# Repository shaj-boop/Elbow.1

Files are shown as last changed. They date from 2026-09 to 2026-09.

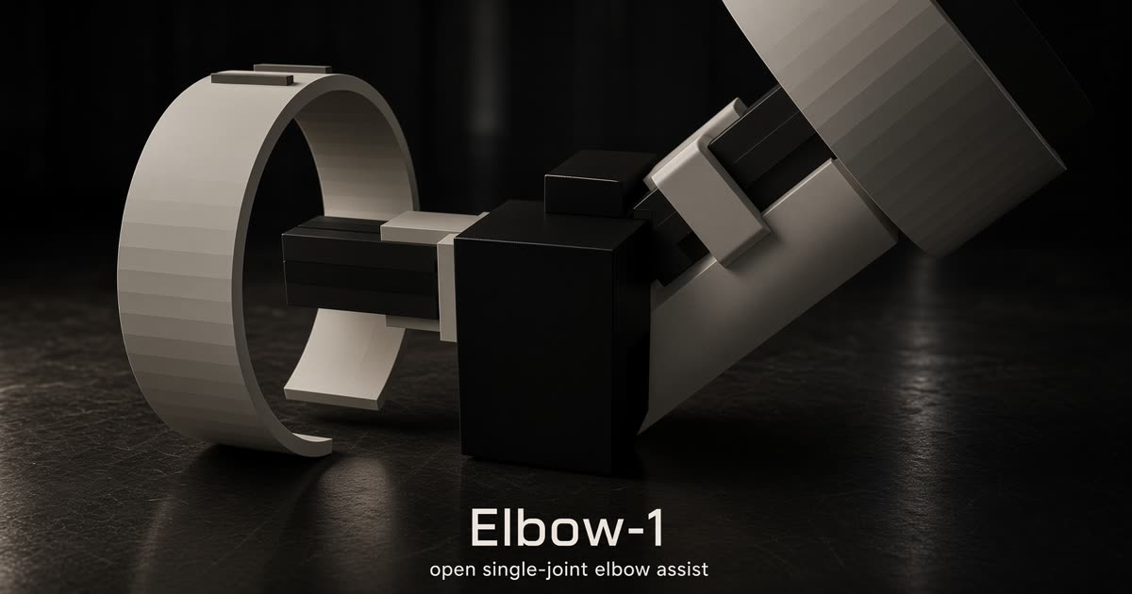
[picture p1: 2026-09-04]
og.jpg

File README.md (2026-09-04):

# Elbow-1

An open single-joint elbow assist. One degree of freedom. One working elbow.

CAD freeze **v0** for a Solo Grant application (ask: **$1,000**). The grant buys two ROBOTIS Dynamixel MX-28AT actuators and the cuff, sensors, and e-stop around them.

Builder: **Dmitrii Naumov**, solo.

**Not a medical device.** Not a clinic product. Not a full-body suit.

| | |
|---|---|
| Stage | CAD + firmware skeleton. Actuators not purchased. |
| Ask | $1,000 |
| DoF | 1 (elbow) |
| Actuators | MX-28AT ×2 (agonist / antagonist) |
| License | CERN-OHL-S v2 (hardware) / MIT (firmware) |

## What v1 is

- One elbow, not a suit
- Two MX-28AT actuators (position + PID in the box, 2.5 N·m stall at 12 V)
- 3D-printed PETG cuffs on a short 2020 aluminum frame
- Load cell in the load path
- Arduino firmware that will not move unless the e-stop is armed
- Bench test: hold 2 kg through 90°, log angle and load to CSV
- Then the same test on an arm

## Repo layout

```
cad/elbow1.scad          OpenSCAD source (parametric)
cad/stl/                 Printable parts
firmware/Elbow1.ino      Arduino + Dynamixel Shield
firmware/config.h        Pins, IDs, torque cap
BOM.md                   Priced parts, Sep 2026
BUILD.md                 Four-week plan after parts land
SAFETY.md                E-stop, torque cap, no medical claims
CONSTRAINTS.md           What v1 will not grow into
GRANT.md                 Written application
FORM_ANSWERS.md          Airtable paste sheet
LICENSE                  CERN-OHL-S / MIT
```

## Print recipe

PETG · 0.2 mm layer · 5 perimeters · 40% gyroid.

| Part | File |
|---|---|
| Upper-arm cuff (ID 96 mm) | `cad/stl/cuff_upper.stl` |
| Forearm cuff (ID 80 mm) | `cad/stl/cuff_forearm.stl` |
| Horn adapter ×2 | `cad/stl/horn_adapter.stl` |
| Load-cell bracket | `cad/stl/loadcell_bracket.stl` |
| Extrusion clip ×2 | `cad/stl/extrusion_clip.stl` |

Open `cad/elbow1.scad` in [OpenSCAD](https://openscad.org). `part = "assembly";` shows the hinge.

## Firmware

Arduino Uno + Dynamixel Shield. Serial 115200.

```
ARM / DISARM / MOVE <deg> / CYCLE / LOG ON
```

Torque stays off until the latching e-stop is armed. See `SAFETY.md`.

## After the money lands

See `BUILD.md`. Order both MX-28ATs on day 0. Week 2 is the 2 kg / 90° bench. Week 4 is publish — or an honest miss.

## Working stage

- [x] Constraint list (one joint, no suit)
- [x] BOM priced with live sources, Sep 2026
- [x] Safety rules
- [x] OpenSCAD assembly + printable STLs
- [x] Arduino firmware skeleton (will not move unarmed)
- [x] Bench protocol: 2 kg through 90°, three cycles, CSV
- [ ] MX-28AT ×2 purchased — this is the wall
- [ ] Week 1: one motor, e-stop in the enable line
- [ ] Week 2: 2 kg / 90° logged on the bench
- [ ] Week 3: PETG cuffs on a padded dummy, then an arm
- [ ] Week 4: publish video + CSV, or an honest miss

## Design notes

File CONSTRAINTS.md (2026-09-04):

# Constraints — what v1 is not

- Not a suit. One elbow.
- Not two arms. Not a shoulder. Not a hand.
- Not Dynamixel-X series, not Maxon, not a custom cycloidal. MX-28AT ×2 is the joint.
- Not CNC aluminum cuffs in v1. PETG + webbing. If PETG cracks, that is data.
- Not ROS as a requirement. Arduino + a serial log on the Mac mini is enough.
- Not a paper. A video, a CSV of angle/load, and the CAD.

If a sentence starts with "later we could add hips," it does not belong in this grant.

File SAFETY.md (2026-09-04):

# Safety — Elbow-1

v1 is a bench joint that may later go on one adult arm. It is not a medical device.

## Hard rules

1. **E-stop is armed or the motors do not enable.** Latching mushroom, wired so a software crash still kills drive.
2. **Torque cap in firmware** below stall. MX-28AT stall is 2.5 N·m at 12 V. v1 command limit is well under that.
3. **No backdrive fight.** If the load cell sees an unexpected spike, disable.
4. **Bench first.** 2 kg through 90° in a fixture, logged, before any worn test.
5. **Worn test is optional and slow.** Padded cuffs, second person present, e-stop in the free hand.
6. **No medical claims.** No rehab protocol. No patient. No "for disability" marketing in v1.

## What this is not

A full-body exo. A factory cobot. A product. A way around a clinic.

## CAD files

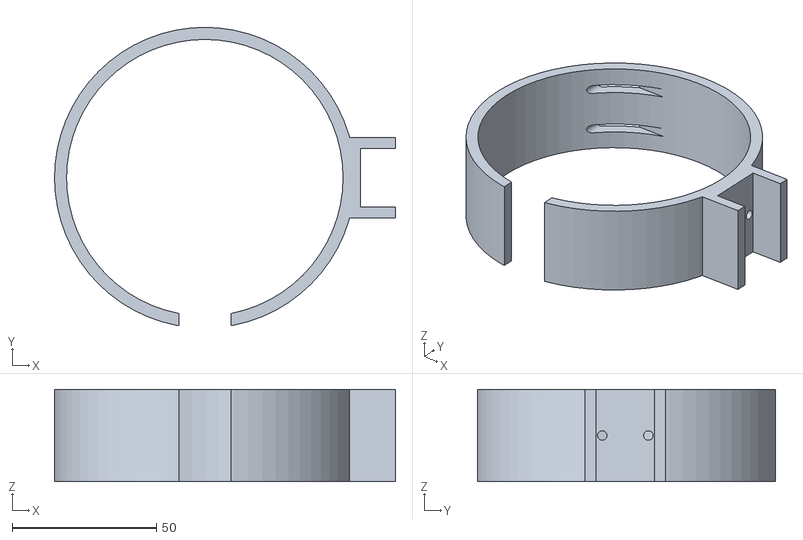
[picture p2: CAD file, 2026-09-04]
cuff_upper.stl
118.4 x 103.6 x 32.0

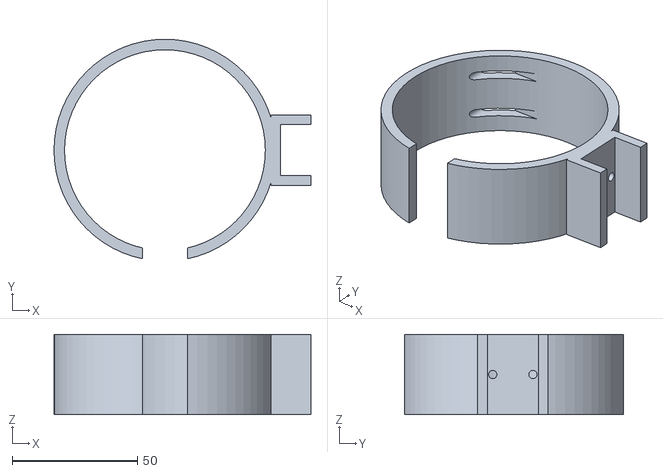
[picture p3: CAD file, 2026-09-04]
cuff_forearm.stl
102.4 x 87.5 x 32.0

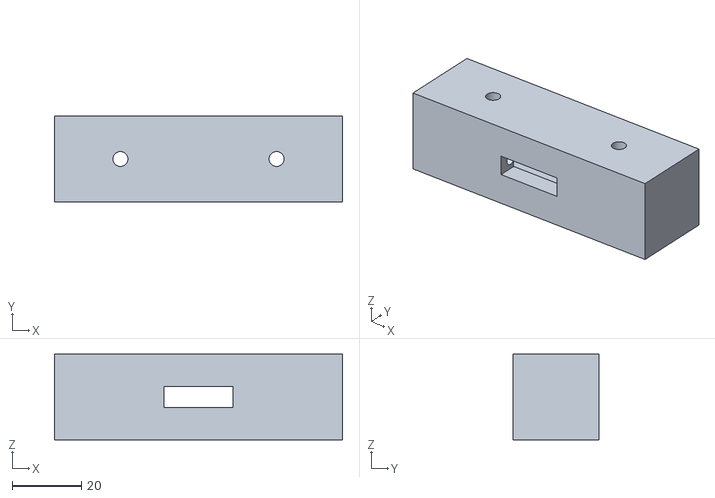
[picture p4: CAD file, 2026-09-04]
loadcell_bracket.stl
83.0 x 24.7 x 24.7

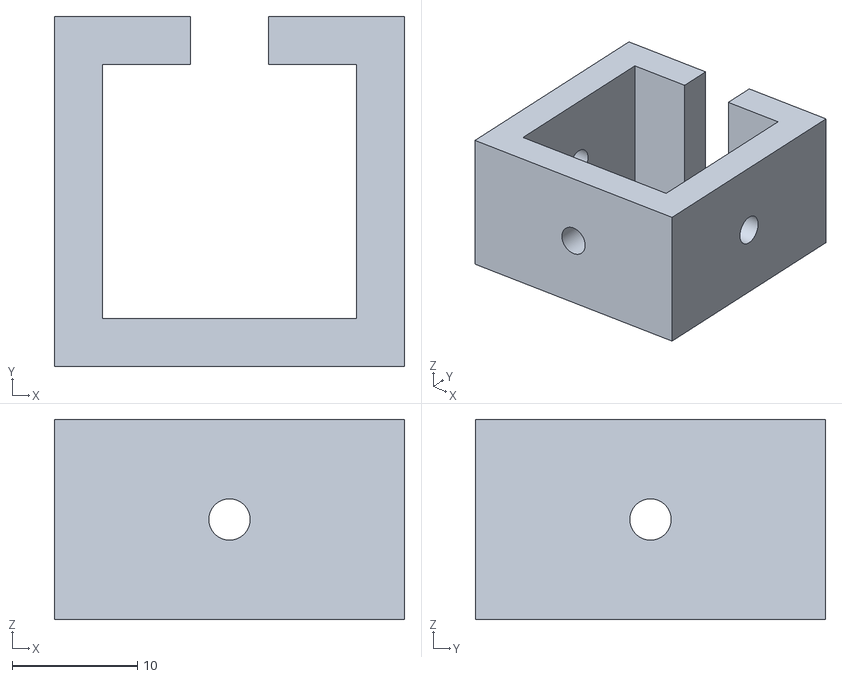
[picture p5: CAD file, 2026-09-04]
extrusion_clip.stl
28.0 x 28.0 x 16.0

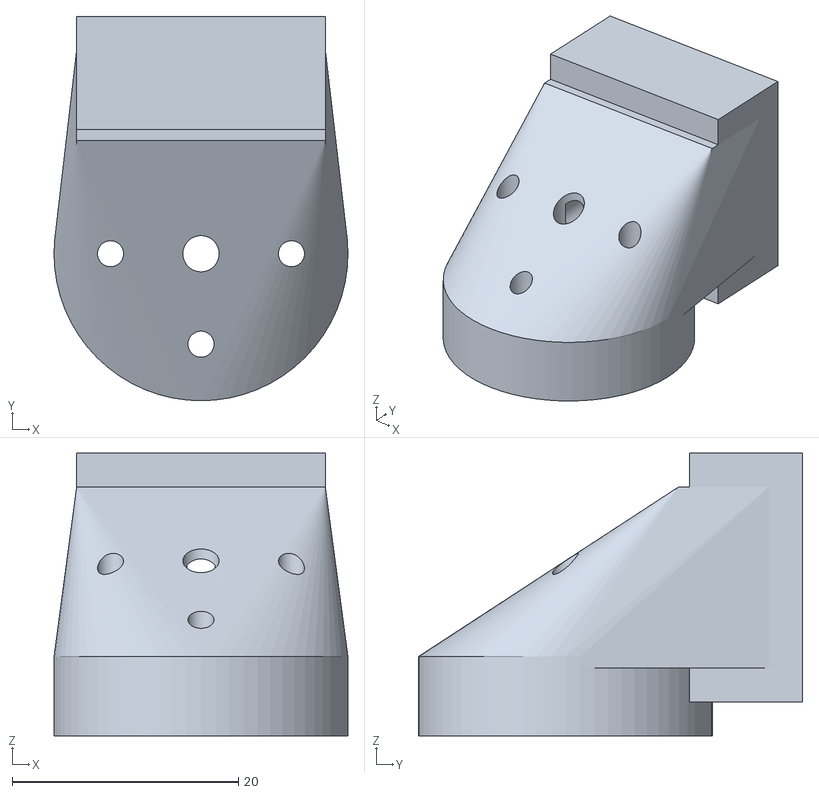
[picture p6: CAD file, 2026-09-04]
horn_adapter.stl
26.0 x 34.0 x 25.0

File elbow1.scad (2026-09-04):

// Elbow-1 — open single-joint elbow assist
// Print PETG, 0.2 mm, 5 perimeters, 40% gyroid.
// MX-28AT body: 35.6 x 50.6 x 35.5 mm (ROBOTIS).
// Units: millimetres. Origin: assembly midline.

$fn = 64;

part = "assembly"; // cuff_upper | cuff_forearm | horn_adapter | loadcell_bracket | extrusion_clip | dummy_mx28 | assembly

// --- MX-28AT ---
mx_w = 35.6;
mx_h = 50.6;
mx_d = 35.5;
horn_r_holes = 8.0;     // M2 holes on MX horn
horn_od = 22.0;
horn_screw = 3.2;

// --- 2020 ---
ext = 20;
ext_slot = 6.2;

// --- load cell 20 kg aluminium bar (typical) ---
lc_l = 75;
lc_w = 12.7;
lc_h = 12.7;
lc_hole = 4.3;
lc_hole_inset = 15;

// --- cuffs (adult) ---
upper_id = 96;
fore_id  = 80;
cuff_t   = 4.2;
cuff_w   = 32;
web_w    = 25;
web_t    = 3.2;

module mx28_dummy() {
    color("#2a2a2a")
        cube([mx_w, mx_d, mx_h], center=true);
    color("#c9a227")
        translate([0, mx_d/2 + 1.2, mx_h*0.18])
            rotate([90,0,0])
                cylinder(h=2.4, d=horn_od, center=true);
}

module horn_adapter() {
    // Sits on MX horn, presents a 2020-facing plate with 4x M3.
    difference() {
        union() {
            cylinder(h=6, d=horn_od + 4);
            translate([0,0,6])
                hull() {
                    cylinder(h=1, d=horn_od + 4);
                    translate([0, 14, 8])
                        cube([22, 8, 16], center=true);
                }
            translate([0, 16, 14])
                cube([22, 10, 22], center=true);
        }
        // horn screw
        translate([0,0,-1]) cylinder(h=20, d=horn_screw);
        // 4x M2 on horn
        for (a = [0:90:270])
            rotate([0,0,a])
                translate([horn_r_holes, 0, -1])
                    cylinder(h=20, d=2.3);
        // 2020 pocket
        translate([0, 22, 14])
            cube([ext + 0.4, 12, ext + 0.4], center=true);
        // M3 through 2020
        translate([0, 16, 14])
            rotate([90,0,0])
                cylinder(h=30, d=3.3, center=true);
        // M3 nut trap
        translate([0, 12, 14])
            rotate([90,0,0])
                cylinder(h=3.2, d=6.2, center=true, $fn=6);
    }
}

module cuff(inner) {
    outer = inner + 2*cuff_t;
    split = 18;
    difference() {
        union() {
            cylinder(h=cuff_w, d=outer);
            // 2020 boss
            translate([outer/2 + 6, 0, cuff_w/2])
                cube([16, 28, cuff_w], center=true);
        }
        translate([0,0,-1]) cylinder(h=cuff_w+2, d=inner);
        // split for flex / webbing close
        translate([0, -outer/2, cuff_w/2])
            cube([split, outer, cuff_w+2], center=true);
        // webbing slots
        for (z = [8, cuff_w-8]) {
            translate([-inner/4, inner/2 - 2, z])
                rotate([90,0,0])
                    hull() {
                        translate([-web_w/2 + 1.5, 0, 0]) cylinder(h=20, d=web_t);
                        translate([ web_w/2 - 1.5, 0, 0]) cylinder(h=20, d=web_t);
                    }
        }
        // M3 pair into 2020 boss
        translate([outer/2 + 6, 8, cuff_w/2])
            rotate([0,90,0]) cylinder(h=24, d=3.3, center=true);
        translate([outer/2 + 6,-8, cuff_w/2])
            rotate([0,90,0]) cylinder(h=24, d=3.3, center=true);
        // 2020 pocket in boss
        translate([outer/2 + 12, 0, cuff_w/2])
            cube([ext+0.3, ext+0.3, cuff_w+2], center=true);
    }
}

module cuff_upper()    { cuff(upper_id); }
module cuff_forearm()  { cuff(fore_id); }

module loadcell_bracket() {
    wall = 4;
    difference() {
        translate([0,0,0])
            cube([lc_l + 8, lc_w + 12, lc_h + wall + 8], center=true);
        // pocket
        translate([0,0, wall/2])
            cube([lc_l + 0.4, lc_w + 0.4, lc_h + 0.4], center=true);
        // through for wiring
        cube([20, lc_w + 14, 6], center=true);
        // M4 holes matching bar
        for (x = [-lc_l/2 + lc_hole_inset, lc_l/2 - lc_hole_inset])
            translate([x, 0, 0])
                cylinder(h=40, d=lc_hole, center=true);
        // M3 to 2020 on the back
        for (y = [-8, 8])
            translate([0, y, 0])
                rotate([0,90,0])
                    cylinder(h=40, d=3.3, center=true);
    }
}

module extrusion_clip() {
    difference() {
        cube([28, 28, 16], center=true);
        cube([ext+0.35, ext+0.35, 18], center=true);
        rotate([90,0,0]) cylinder(h=40, d=3.3, center=true);
        rotate([0,90,0]) cylinder(h=40, d=3.3, center=true);
        // slot mouths
        translate([0, ext/2 + 4, 0]) cube([ext_slot, 10, 18], center=true);
    }
}

module assembly() {
    // two MX-28 as agonist / antagonist about the elbow axis
    translate([0,  28, 0]) rotate([0,90,0]) mx28_dummy();
    translate([0, -28, 0]) rotate([0,90,180]) mx28_dummy();
    color("#d8d2c4") {
        translate([-70, 0, 42]) rotate([90,0,90]) cuff_upper();
        translate([ 78, 0, 36]) rotate([90,0,90]) cuff_forearm();
        translate([0, 28, mx_h/2 + 8]) horn_adapter();
        translate([0,-28, mx_h/2 + 8]) rotate([0,0,180]) horn_adapter();
        translate([0, 0, -36]) loadcell_bracket();
        translate([-40, 0, 10]) extrusion_clip();
        translate([ 40, 0, 10]) extrusion_clip();
    }
    // 2020 spars (visual)
    color("#8a8a8a") {
        translate([-48, 0, 10]) cube([80, 20, 20], center=true);
        translate([ 52, 0, 10]) cube([70, 20, 20], center=true);
    }
}

if (part == "cuff_upper")       cuff_upper();
else if (part == "cuff_forearm") cuff_forearm();
else if (part == "horn_adapter") horn_adapter();
else if (part == "loadcell_bracket") loadcell_bracket();
else if (part == "extrusion_clip") extrusion_clip();
else if (part == "dummy_mx28")   mx28_dummy();
else                            assembly();

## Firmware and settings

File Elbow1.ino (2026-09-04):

// Elbow-1 firmware v0.1 — Arduino Uno + Dynamixel Shield
// Will not enable torque unless the e-stop is armed.
//
// Serial 115200. Commands:
//   ARM          — torque on if e-stop is high
//   DISARM       — torque off
//   MOVE <deg>   — 0..90, both actuators, torque-capped
//   CYCLE        — three 0→90→0 sweeps (Week 2 protocol)
//   LOG ON|OFF   — CSV: t_ms,angle_deg,load_n,flex,ext,estop
//
// If it fails, the failure is in the log too.

#include <Dynamixel2Arduino.h>
#include "HX711.h"
#include "config.h"

Dynamixel2Arduino dxl(DXL_SERIAL, DXL_DIR_PIN);
HX711 scale;

bool armed = false;
bool logging = false;
uint32_t t0 = 0;
float goalDeg = 0;

uint16_t degToTick(float deg) {
  if (deg < 0) deg = 0;
  if (deg > 90) deg = 90;
  return (uint16_t)(POS_ZERO + deg * (TICKS_PER_REV / 360.0f));
}

bool estopArmed() {
  return digitalRead(ESTOP_PIN) == HIGH;
}

void torqueOff() {
  dxl.torqueOff(ID_FLEX);
  dxl.torqueOff(ID_EXT);
  armed = false;
  digitalWrite(LED_ARMED, LOW);
}

bool torqueOn() {
  if (!estopArmed()) {
    torqueOff();
    Serial.println(F("# ESTOP open — not arming"));
    return false;
  }
  dxl.writeControlTableItem(TORQUE_LIMIT, ID_FLEX, TORQUE_LIMIT);
  dxl.writeControlTableItem(TORQUE_LIMIT, ID_EXT,  TORQUE_LIMIT);
  dxl.torqueOn(ID_FLEX);
  dxl.torqueOn(ID_EXT);
  armed = true;
  digitalWrite(LED_ARMED, HIGH);
  Serial.println(F("# armed"));
  return true;
}

void goDeg(float deg) {
  if (!armed) return;
  goalDeg = deg;
  uint16_t t = degToTick(deg);
  dxl.setGoalPosition(ID_FLEX, t);
  dxl.setGoalPosition(ID_EXT,  TICKS_PER_REV - t); // antagonist
}

float readLoadN() {
  if (!scale.is_ready()) return 0;
  return scale.get_units(1) * 9.80665f / 1000.0f; // gram-ish cal → N
}

void setup() {
  pinMode(ESTOP_PIN, INPUT_PULLUP);
  pinMode(LED_ARMED, OUTPUT);
  digitalWrite(LED_ARMED, LOW);

  Serial.begin(115200);
  dxl.begin(DXL_BAUD);
  dxl.setPortProtocolVersion(DXL_PROTOCOL);

  scale.begin(HX711_DOUT, HX711_SCK);
  scale.set_scale(1.0f / SCALE_N_PER_COUNT);
  scale.tare();

  torqueOff();
  Serial.println(F("# Elbow-1 v0.1  e-stop must be armed"));
  Serial.println(F("t_ms,angle_deg,load_n,flex,ext,estop"));
  t0 = millis();
}

void loop() {
  if (!estopArmed() && armed) {
    torqueOff();
    Serial.println(F("# ESTOP — torque off"));
  }

  float load = readLoadN();
  if (armed && fabs(load) > SPIKE_N) {
    torqueOff();
    Serial.print(F("# spike N="));
    Serial.println(load);
  }

  if (logging && (millis() % LOG_MS) < 2) {
    Serial.print(millis() - t0); Serial.print(',');
    Serial.print(goalDeg); Serial.print(',');
    Serial.print(load, 3); Serial.print(',');
    Serial.print(dxl.getPresentPosition(ID_FLEX)); Serial.print(',');
    Serial.print(dxl.getPresentPosition(ID_EXT)); Serial.print(',');
    Serial.println(estopArmed() ? 1 : 0);
  }

  if (Serial.available()) handleLine();
}

void handleLine() {
  String line = Serial.readStringUntil('\n');
  line.trim();
  if (line.equalsIgnoreCase("ARM")) { torqueOn(); return; }
  if (line.equalsIgnoreCase("DISARM")) { torqueOff(); return; }
  if (line.startsWith("MOVE")) {
    goDeg(line.substring(4).toFloat());
    return;
  }
  if (line.equalsIgnoreCase("CYCLE")) {
    if (!torqueOn()) return;
    logging = true;
    for (uint8_t c = 0; c < 3; c++) {
      goDeg(90); delay(2500);
      goDeg(0);  delay(2500);
    }
    torqueOff();
    Serial.println(F("# cycle done"));
    return;
  }
  if (line.equalsIgnoreCase("LOG ON"))  { logging = true;  t0 = millis(); }
  if (line.equalsIgnoreCase("LOG OFF")) { logging = false; }
}

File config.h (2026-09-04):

#pragma once
// Elbow-1 — pin map and hard limits.
// MX-28AT stall is 2.5 N·m at 12 V. Command cap sits well under that.

#include <stdint.h>

static const uint8_t ID_FLEX = 1;
static const uint8_t ID_EXT  = 2;

// Dynamixel Shield on Uno: UART via the onboard buffer.
#define DXL_SERIAL   Serial
#define DXL_DIR_PIN  2
static const float DXL_PROTOCOL = 1.0f;
static const uint32_t DXL_BAUD  = 1000000;

// MX-28: 12-bit, 4096 ticks / rev.
static const uint16_t TICKS_PER_REV = 4096;
static const uint16_t POS_ZERO      = 2048;          // 0°
static const uint16_t POS_FLEX90    = 2048 + 1024;   // 90°

// Torque cap: 1.2 N·m ≈ 48% of stall. Register units 0–1023.
static const uint16_t TORQUE_LIMIT = 490;

// Latching mushroom. Hardware cuts enable; this pin only senses it.
// HIGH = armed. LOW = pressed / open loop / crash-safe disable.
static const uint8_t ESTOP_PIN = 4;

// HX711 on the 20 kg bar in the load path.
static const uint8_t HX711_DOUT = A1;
static const uint8_t HX711_SCK  = A0;
static const float   SCALE_N_PER_COUNT = 0.0024f; // calibrate on the 2 kg mass
static const float   SPIKE_N = 40.0f;             // unexpected load → disable

static const uint8_t LED_ARMED = 13;
static const uint16_t LOG_MS   = 20;              // 50 Hz CSV
